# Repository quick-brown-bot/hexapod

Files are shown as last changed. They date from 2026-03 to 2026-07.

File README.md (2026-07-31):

# Hexapod

An ESP32-powered hexapod robot built as a long-term robotics and embedded systems project.

The goal is not just to make a robot walk, but to learn and at the same time build a platform that is easy to experiment with, tune, and extend. Most robot behavior is configurable at runtime, control inputs are transport-independent, and the motion stack is organized into separated components.

The project combines firmware, hardware design, and system documentation in a single repository.

> 6 legs, 18 servos, ESP32, ESP-IDF, FreeRTOS, direct PWM.

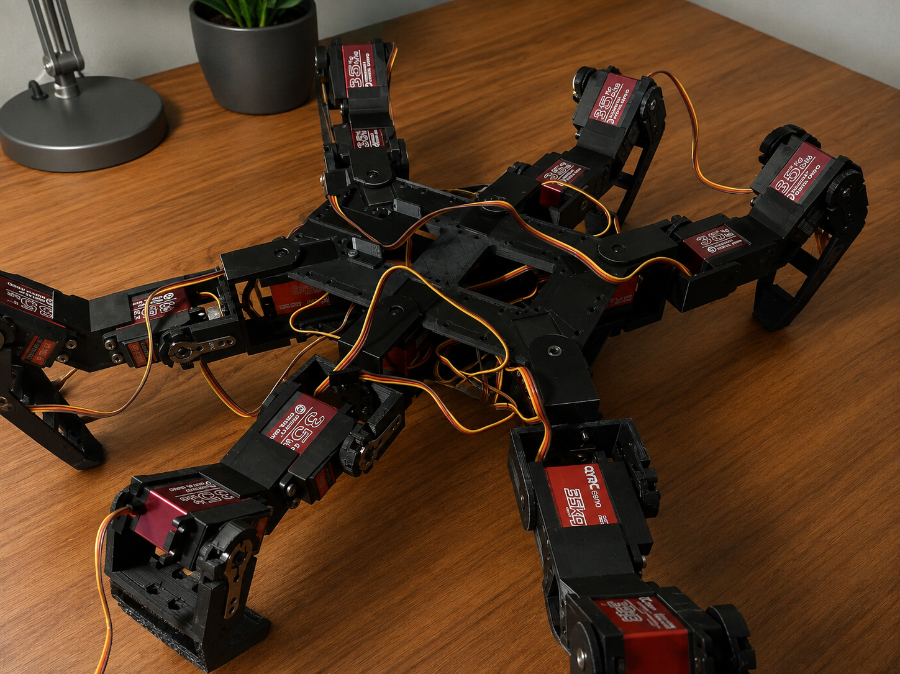
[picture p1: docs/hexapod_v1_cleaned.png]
Hexapod V1


The distributed RS485/RP2040 leg-controller generation of this project has moved to a separate repository: [quick-brown-bot/hexapod_v2](https://github.com/quick-brown-bot/hexapod_v2). This repo covers the original ESP32 direct-PWM robot only. V1 is closed: the hardware and firmware here are done and kept for reference and continued use, not further development.

---

## What Is In This Repository

The repository contains software and hardware assets used to develop and validate the robot.

```text
firmware/
└── mainboard/         Main robot firmware (ESP32, direct PWM)

hardware/
├── servo_mainboard/   Central ESP32 board driving the servos directly
├── leg/               Leg controller board
├── esp32_connector/   ESP32 carrier / breakout
├── symbols/           Symbol libraries
├── footprints/        Footprint libraries
└── models/            Mechanical models

docs/
├── common/            Docs shared across subsystems (RPC, WiFi, config)
├── architecture/       System and hardware architecture docs
├── development/        Development docs
└── plans/             Project-wide backlog and research items
```

Mainboard firmware overview: [firmware/mainboard/README.md](firmware/mainboard/README.md)

The main firmware is built around a fixed 100 Hz control loop and a modular motion pipeline:

```text
Controller Input
        ↓
Gait Scheduler
        ↓
Foot Trajectory Generation
        ↓
Inverse Kinematics
        ↓
Motion Limiting
        ↓
Servo Outputs
```

---

## Current Technical Highlights

## Effort Summary

| Effort Area | Scope | Current Status | Notes |
| --- | --- | --- | --- |
| Locomotion Pipeline | Command mapping, gait scheduler, swing trajectory, whole-body IK | Implemented | Runs in a fixed 100 Hz control loop |
| KPP Motion Limits | Velocity, acceleration, jerk limiting and state estimation | Implemented | Runtime limits are configuration-backed |
| Controller Abstraction | Driver-agnostic core plus transport-specific drivers | Implemented | FlySky iBUS, Wi-Fi TCP, and Bluetooth Classic paths are present |
| RPC System | Queue-based command processing and config control | Implemented | Live inspection and runtime tuning are available |
| Configuration Platform | Namespace defaults, migration, discovery, persistence | Implemented | Core runtime namespaces are already consumed by modules |
| Configurator Tooling | External tuning and visualization UX | Planned | Firmware-side groundwork exists; UI work remains |

## Hardware Snapshot

- MCU: ESP32 running FreeRTOS through ESP-IDF.
- Robot layout: 6 legs, 3 degrees of freedom per leg, 18 hobby servos total.
- Power: 4S LiPo, separate UBEC paths for servo and logic power.
- PWM: mixed MCPWM and LEDC to reach all 18 outputs on the ESP32.
- Mechanical: custom 3D-printed chassis and leg parts.

## High-Level Architecture

```mermaid
flowchart LR
        Control[Controller stack]
        Config[RPC and config]
        App[Application loop]
        Loc[Locomotion]
        Limits[Motion limiting]
        Act[Actuation]
        Robot[Robot hardware]

        Control --> App
        Config --> App
        App --> Loc --> Limits --> Act --> Robot
        Config --> Control
```

- Controller stack: receives operator input from supported transports and normalizes it.
- RPC and config: handles runtime commands, parameter discovery, persistence, and save flows.
- Application loop: owns boot order and the 100 Hz control cycle.
- Locomotion: turns operator intent into gait phase, foot targets, and joint-space commands.
- Motion limiting: constrains commanded motion to configured dynamic envelopes.
- Actuation: maps joint commands to the PWM outputs that drive the robot.

### Runtime Configuration

Configuration is treated as a first-class subsystem rather than a collection of compile-time constants.

Parameters are organized into namespaces. Each namespace owns:

- parameter definitions,
- default values,
- validation rules,
- persistence behavior,
- migration logic,
- RPC discovery metadata.

The configuration manager provides:

- runtime parameter inspection,
- runtime modification,
- save/load operations,
- namespace registration,
- NVS persistence,
- version-aware migration support.

Robot geometry, calibration data, controller settings, motion limits, and other runtime behavior are loaded through this system rather than being hardcoded throughout the codebase.

### Motion Pipeline

The locomotion stack converts user commands into joint targets through a sequence of dedicated subsystems:

- gait scheduling,
- swing trajectory generation,
- inverse kinematics,
- velocity limiting,
- acceleration limiting,
- jerk limiting,
- servo actuation.

The motion loop runs at 100 Hz.

### Controller Abstraction

Controller transports are separated from locomotion.

Supported ingress paths currently include:

- FlySky iBUS,
- Wi-Fi TCP,
- Bluetooth Classic.

Each transport driver translates incoming data into a normalized controller state consumed by the motion system.

This allows locomotion, gait generation, and motion limiting to remain independent of transport-specific protocols.

### Hardware-Aware Design

The robot uses 18 servos arranged as three joints per leg:

- Coxa
- Femur
- Tibia

Servo signal generation is implemented on ESP32 using a combination of MCPWM and LEDC peripherals to fit within available hardware resources.

Power for logic and servos is separated to improve stability under heavy load.

---

## Engineering Problems Being Explored

This project is primarily a learning and engineering platform.

Current focus areas include:

- real-time control on resource-constrained hardware,
- gait generation and scheduling,
- inverse kinematics,
- motion smoothing and trajectory constraints,
- configuration architecture for embedded systems,
- transport-independent control interfaces,
- robotics software maintainability,
- practical servo-driven locomotion.

---

## Documentation

The repository contains detailed documentation covering implementation details and architecture decisions.

- [docs/architecture/SYSTEM_ARCHITECTURE.md](docs/architecture/SYSTEM_ARCHITECTURE.md)
- [docs/architecture/HARDWARE_AND_MECHANICS.md](docs/architecture/HARDWARE_AND_MECHANICS.md)
- [firmware/mainboard/README.md](firmware/mainboard/README.md)

**Common:**
- [docs/common/interfaces/RPC_USER_GUIDE.md](docs/common/interfaces/RPC_USER_GUIDE.md)
- [docs/common/configuration/CONFIGURATION_PERSISTENCE_DESIGN.md](docs/common/configuration/CONFIGURATION_PERSISTENCE_DESIGN.md)

Full documentation index: [docs/README.md](docs/README.md)

---

## Project Status

The project is under active development.

Current work focuses on improving locomotion quality, refining control architecture boundaries, and preparing the next generation of leg electronics while keeping the existing robot operational as a test platform.

---

## License

This repository uses Apache License 2.0 for the mainboard firmware.

License file location: [LICENSE](LICENSE)

Include the following notice in derivative works:

```text
Copyright 2025 Pawel Grudzien

Licensed under the Apache License, Version 2.0 (the "License");
you may not use this file except in compliance with the License.
You may obtain a copy of the License at

    http://www.apache.org/licenses/LICENSE-2.0

Unless required by applicable law or agreed to in writing, software
distributed under the License is distributed on an "AS IS" BASIS,
WITHOUT WARRANTIES OR CONDITIONS OF ANY KIND, either express or implied.
See the License for the specific language governing permissions and
limitations under the License.
```

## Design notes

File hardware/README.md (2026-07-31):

# Hexapod boards

The electrical design: a centralized controller that drives the servos directly.

This folder is self-contained — its own copy of the symbol libraries and
footprints lives alongside the designs, so the boards do not depend on any
shared top-level libraries.

| Board | Files | Role |
|---|---|---|
| [servo_mainboard](servo_mainboard/) | `hexapod.kicad_*` | Central ESP32 board driving the servos directly. |
| [leg](leg/) | `leg_v2.kicad_*` | XIAO RP2040 leg controller (early distributed-leg experiment). |
| [esp32_connector](esp32_connector/) | `esp32_connector.kicad_*` | ESP32 carrier / breakout. |

## Layout

```
hardware/
├── symbols/      ← Seeed XIAO + SymbolsLib (ESP32) symbol libraries
├── footprints/   ← Seeed XIAO footprints
├── models/       ← hexapod_v1.FCStd (mechanical model)
├── servo_mainboard/
├── leg/
└── esp32_connector/
```

The board project library tables (`sym-lib-table` / `fp-lib-table`) reference
these local copies via `${KIPRJMOD}`-relative paths. Stock KiCad symbols
(`Device:*`, `Connector:*`, `RF_Module:*`, `power:*`) resolve from the KiCad
install's global library table.

These schematics are KiCad-native and edited in Eeschema.

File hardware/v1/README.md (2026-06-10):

# Hexapod V1 boards

The original (Version 1) electrical design: a centralized controller that drives
the servos directly, before the V2 split into distributed leg controllers and a
separate power-distribution board. Kept as-is for reference and continued use.

This folder is self-contained — its own copy of the symbol libraries and
footprints lives alongside the designs, so the V1 boards do not depend on any
shared top-level libraries.

| Board | Files | Role |
|---|---|---|
| [servo_mainboard](servo_mainboard/) | `hexapod.kicad_*` | Central ESP32 board driving the servos directly. |
| [leg](leg/) | `leg_v2.kicad_*` | XIAO RP2040 leg controller (early distributed-leg experiment). |
| [esp32_connector](esp32_connector/) | `esp32_connector.kicad_*` | ESP32 carrier / breakout. |

## Layout

```
hardware/v1/
├── symbols/      ← Seeed XIAO + SymbolsLib (ESP32) symbol libraries
├── footprints/   ← Seeed XIAO footprints
├── models/       ← hexapod_v1.FCStd (mechanical model)
├── servo_mainboard/
├── leg/
└── esp32_connector/
```

The board project library tables (`sym-lib-table` / `fp-lib-table`) reference
these local copies via `${KIPRJMOD}`-relative paths. Stock KiCad symbols
(`Device:*`, `Connector:*`, `RF_Module:*`, `power:*`) resolve from the KiCad
install's global library table.

> V1 schematics are KiCad-native and edited in Eeschema. The schematic-as-code
> toolchain (`hardware/schematic/`) and the as-code workflow apply to the
> [V2 boards](../v2/README.md).

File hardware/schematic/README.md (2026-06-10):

# `hardware/schematic` — schematics as code

Author and maintain the KiCad schematics in `hardware/` from Python instead of
hand-editing `.kicad_sch` files in Eeschema. The point is **UUID stability**: the
PCB references each symbol by `<root_uuid>/<symbol_uuid>`, so as long as those
UUIDs are preserved across regenerations, your board layout (placement + routing)
is never lost. A committed `uuids.json` per board is what guarantees that.

> Update the board's documentation in the same change as any schematic edit. See
> `.claude/skills/hardware-schematics/SKILL.md` for the full workflow and rules.

## Modules

| File | What it is |
|---|---|
| `sexpr.py` | Lossless S-expression parser + KiCad-faithful serializer. Round-trips a board's `.kicad_sch` byte-for-byte. |
| `registry.py` | `UuidRegistry` — maps stable keys (`sym:U1`, `root:leg_v2`, …) to UUIDs in `uuids.json`. Committed, never hand-edited. |
| `schematic.py` | `Schematic` DSL — load/new, `place`, `wire`, `junction`, `label`, `net`, `set_value`. Resolves pin world-coordinates for all symbol rotations. |
| `migrate.py` | One-time per board: freezes the original, seeds the registry, emits the source-of-truth script. |

## Per-board files (after migration)

```
hardware/<board>/
├── <board>_sch.py        ← source of truth — EDIT this
├── <board>.base.kicad_sch ← frozen migration capture — do not edit / open in KiCad
├── uuids.json            ← committed UUID registry — never hand-edit
└── <board>.kicad_sch     ← generated — open THIS in KiCad to lay out the PCB
```

The script loads the frozen `.base`, applies your Python edits, and writes the
working `.kicad_sch`. Loading an immutable base (not the file it writes) keeps
regeneration deterministic and idempotent.

## Workflow

Migrate a board (the boards under `hardware/` are not migrated yet):

```bash
python -m hardware.schematic.migrate hardware/leg/leg_v2.kicad_sch
```

Edit and regenerate:

```bash
# edit hardware/leg/leg_v2_sch.py, then:
python hardware/leg/leg_v2_sch.py
git diff hardware/leg/uuids.json     # additions only — never modified values
```

Then in KiCad: open the regenerated `.kicad_sch`, run ERC, *Update PCB from
Schematic*. Existing parts keep their placement; only new parts appear unplaced.

## Example edit

```python
def build():
    reg = UuidRegistry(HERE / "uuids.json")
    sch = Schematic.load(HERE / "leg_v2.base.kicad_sch", reg, name="leg_v2")

    # add a status LED off the RP2040; connect by net label (no wires needed)
    sch.import_lib_symbol(R_SMALL_LIB, "Device:R_Small")
    sch.import_lib_symbol(LED_LIB, "Device:LED_Small")
    r = sch.place("Device:R_Small",   "R10", at=(60, 50), value="470", rotation=90)
    d = sch.place("Device:LED_Small", "D10", at=(60, 60))
    sch.net("STATUS", [r.pin("2"), d.pin("A")])

    return sch
```

`place()` requires the symbol definition to be present in the sheet; for a part not
already used on the board, `import_lib_symbol(<.kicad_sym path>, <lib_id>)` copies it
from a KiCad symbol library first.

## Guarantees (and what's verified)

- **Byte-exact round-trip** of all three existing boards (`sexpr`), so migration
  introduces **zero** UUID churn.
- **Pin geometry** validated against real wire endpoints for rotations 0/90/180/270.
- **Idempotent** regeneration: running a board script twice yields identical output.

## Limits

- No auto-routing/placement — give wire coordinates or (better) connect by net label.
- New symbol types need their pin data imported from a `.kicad_sym` library.
- Single-sheet only (no hierarchical sheets yet).
- Once migrated, make schematic changes in Python, not in Eeschema — direct
  Eeschema edits to the schematic would be overwritten on the next regenerate.
  (PCB layout is separate and is preserved.)

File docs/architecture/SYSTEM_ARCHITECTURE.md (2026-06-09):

# Hexapod System Architecture

## Purpose

This document is the current-state architecture reference for the firmware in this repository.

It describes:
- which ESP-IDF components make up the system,
- how data moves through the runtime,
- where configuration and transport boundaries live,
- which architectural rules are expected to remain stable.

## 1. System At A Glance

The firmware is split into explicit ESP-IDF components under `components/`, with `main/` responsible for top-level boot ordering and task orchestration.

```mermaid
flowchart LR
    App[main app bootstrap and loop]

    subgraph Motion[Motion Stack]
        Loc[hex_locomotion]
        Lim[hex_motion_limits]
        Act[hex_actuation]
        Kin[hex_kinematics]
        RobotCfg[hex_robot_config]
    end

    subgraph Control[Controller and Transport]
        Core[hex_controller_core]
        Fly[hex_controller_driver_flysky_ibus]
        WifiDrv[hex_controller_driver_wifi_tcp]
        BtDrv[hex_controller_driver_bt_classic]
        WifiAp[hex_wifi_ap]
    end

    subgraph RPC[RPC and Config]
        RpcCore[hex_rpc_core]
        RpcTx[hex_rpc_transport]
        CfgMgr[hex_config_manager]
        Shared[hex_shared_types]
    end

    App --> Loc --> Lim --> Act
    Loc --> Kin
    Loc --> RobotCfg
    Lim --> Kin
    Lim --> RobotCfg
    Act --> RobotCfg

    Fly --> Core
    WifiDrv --> Core
    BtDrv --> Core
    WifiDrv --> RpcTx
    BtDrv --> RpcTx
    WifiAp --> WifiDrv

    RpcCore --> RpcTx
    RpcCore --> CfgMgr
    RpcCore --> Core

    Shared --> Core
    Shared --> RpcCore
    Shared --> RobotCfg
```

## 2. Architectural Layers

### 2.1 Application Bootstrap

Owned by `main/`.

Responsibilities:
- initialize configuration and persistent storage access,
- start RPC and transport-facing services,
- initialize robot runtime dependencies,
- run the fixed-step locomotion loop.

This layer wires components together but should avoid re-implementing component logic.

### 2.2 Motion Stack

The motion stack converts a normalized user command into limited servo outputs.

Components:
- `hex_locomotion`: user command mapping, gait scheduling, swing target generation, whole-body control.
- `hex_motion_limits`: KPP-based velocity, acceleration, and jerk limiting plus state estimation.
- `hex_actuation`: joint command to PWM output translation and peripheral driving.
- `hex_kinematics`: math-only leg kinematics primitives.
- `hex_robot_config`: geometry, mount pose, joint calibration, and servo mapping consumption.

Design intent:
- `hex_kinematics` stays hardware-agnostic.
- `hex_actuation` is the only layer that touches servo driver peripherals.
- `hex_robot_config` projects namespace-backed runtime configuration into motion consumers.

### 2.3 Controller And Transport Stack

This stack decouples controller transport details from locomotion.

Components:
- `hex_controller_core`: normalized channel state, connection state, failsafe behavior, and decode helpers.
- `hex_controller_driver_flysky_ibus`: FlySky ingress.
- `hex_controller_driver_wifi_tcp`: Wi-Fi TCP ingress and RPC forwarding.
- `hex_controller_driver_bt_classic`: Bluetooth Classic ingress and RPC forwarding.
- `hex_wifi_ap`: Wi-Fi AP bring-up and naming policy.

Design intent:
- locomotion reads normalized controller state only,
- transport drivers never call motion modules directly,
- transport-specific framing stays at the driver edge.

### 2.4 RPC And Configuration Stack

This stack owns text command ingress, parameter discovery, persistence, and save flows.

Components:
- `hex_rpc_transport`: transport-neutral RX/TX queueing and sender registration.
- `hex_rpc_core`: parser, dispatcher, and runtime command handling.
- `hex_config_manager`: namespace registry, defaults, validation, load/save, migration, and NVS persistence.
- `hex_shared_types`: cross-component enums and shared structs.

Design intent:
- RPC should operate through public service APIs, not transport internals.
- configuration defaults and persistence behavior should have a single authoritative definition.
- runtime consumers should fail fast when required namespace-backed configuration is unavailable instead of silently falling back to hidden local defaults.

## 3. Runtime Flows

### 3.1 Boot Flow

Boot sequence at a high level:

1. Initialize configuration manager and make namespace state available.
2. Start RPC transport/core services.
3. Bring up Wi-Fi AP and transport-facing controller services as configured.
4. Initialize robot runtime modules that consume loaded configuration.
5. Enter the periodic locomotion loop.

The important architectural point is ordering: configuration and communication services come up before consumers that depend on namespace-backed runtime values.

### 3.2 10 ms Locomotion Loop Execution Flow

The main control loop runs at 100 Hz and follows a single dominant pipeline:

```mermaid
flowchart TD
    Poll[user_command_poll]
    Sched[gait_scheduler_update]
    Swing[swing_trajectory_generate]
    Control[whole_body_control_compute]
    Limit[kpp_apply_limits]
    Execute[robot_execute]
    State[kpp_update_state]

    Poll --> Sched --> Swing --> Control --> Limit --> Execute --> State
```

Per-stage role:

1. `user_command_poll` reads normalized controller state and produces `user_command_t`.
2. `gait_scheduler_update` advances phase and support/swing state.
3. `swing_trajectory_generate` produces body-frame foot targets.
4. `whole_body_control_compute` transforms targets into leg-local frames and solves IK.
5. `kpp_apply_limits` constrains joint commands to configured motion envelopes.
6. `robot_execute` maps commands to servo outputs.
7. `kpp_update_state` updates estimated motion state from the command stream.

### 3.3 10 ms Locomotion Loop Information Flow

The same control loop can also be viewed as a data-transformation pipeline. In this view, the important question is not only what runs next, but which runtime state each stage consumes and which outputs it produces.

```mermaid
flowchart LR
    ControllerState[Normalized controller state]
    UserCmd[user_command_t]
    SchedState[Scheduler state\nphase + support/swing]
    FootTargets[Body-frame foot targets]
    JointDesired[Desired joint command set]
    JointLimited[Limited joint command set]
    PwmOut[Servo PWM outputs]
    EstState[Estimated motion state]

    Core[hex_controller_core]
    Loc[hex_locomotion]
    Lim[hex_motion_limits]
    Act[hex_actuation]
    Kin[hex_kinematics]
    RobotCfg[hex_robot_config]
    CfgMgr[hex_config_manager]

    Core --> ControllerState
    ControllerState --> Loc
    Loc --> UserCmd
    UserCmd --> Loc
    Loc --> SchedState
    SchedState --> Loc
    UserCmd --> FootTargets
    Loc --> FootTargets

    FootTargets --> Loc
    RobotCfg --> Loc
    Kin --> Loc
    CfgMgr --> RobotCfg
    Loc --> JointDesired

    JointDesired --> Lim
    CfgMgr --> Lim
    RobotCfg --> Lim
    Lim --> JointLimited
    JointDesired --> EstState
    Lim --> EstState

    JointLimited --> Act
    RobotCfg --> Act
    Act --> PwmOut
```

Data-flow interpretation:

1. `hex_controller_core` exposes normalized controller state, which `user_command_poll` converts into `user_command_t`.
2. `gait_scheduler_update` consumes the user command and produces scheduler phase plus support/swing state.
3. `swing_trajectory_generate` consumes the user command and scheduler state to produce body-frame foot targets.
4. `whole_body_control_compute` consumes foot targets together with robot geometry and mount data from `hex_robot_config`, and kinematic solving support from `hex_kinematics`, to produce the desired joint command set.
5. `kpp_apply_limits` consumes desired joint commands together with runtime limit configuration to produce the limited joint command set.
6. `robot_execute` consumes the limited joint command set together with projected robot configuration to produce the actual PWM outputs.
7. `kpp_update_state` derives estimated motion state from the command stream after the loop update.

### 3.4 RPC And Config Flow

RPC and persistence are queue-oriented and transport-neutral.

```mermaid
flowchart LR
    subgraph Drivers[Transport Drivers]
        Wifi[Wi-Fi TCP]
        Bt[Bluetooth Classic]
    end

    RxQ[[RPC RX Queue]]
    RpcTask[RPC task]
    Parser[Command parser and dispatcher]
    Config[hex_config_manager]
    TxQ[[RPC TX Queue]]
    Senders[Registered transport senders]

    Wifi --> RxQ
    Bt --> RxQ
    RxQ --> RpcTask --> Parser --> Config
    Parser --> TxQ --> Senders
```

This keeps command semantics centralized even when multiple ingress paths exist.

## 4. Component Ownership Summary

### Motion And Robot Behavior

- `hex_locomotion`: high-level motion intent to desired body/leg targets.
- `hex_motion_limits`: dynamic command conditioning and state estimation.
- `hex_actuation`: hardware-facing servo output generation.
- `hex_kinematics`: reusable leg math.
- `hex_robot_config`: geometry, mounts, calibration, and servo map projection.

### Input, Transport, And Control

- `hex_controller_core`: canonical controller state and decode path.
- `hex_controller_driver_*`: transport-specific ingress and forwarding.
- `hex_wifi_ap`: Wi-Fi service availability.

### RPC, Configuration, And Shared Contracts

- `hex_rpc_transport`: transport-neutral queues and sender plumbing.
- `hex_rpc_core`: command handling and operational RPC behavior.
- `hex_config_manager`: namespace-based configuration platform.
- `hex_shared_types`: shared enums/types that should not be duplicated across components.

## 5. Dependency Rules

These rules define the expected architecture boundary and are more important than exact file placement.

- Motion components must not depend on transport-specific controller drivers.
- Transport drivers must not call locomotion modules directly.
- Hardware peripheral access for servo output belongs in `hex_actuation`, not in locomotion or kinematics.
- Kinematics code should remain usable without hardware dependencies.
- RPC command handling should rely on public controller/config APIs rather than internal transport details.
- Shared enums and cross-component data contracts should live in `hex_shared_types` or the owning public component, not in duplicated private headers.

## 6. Configuration Architecture Position

Configuration is not an auxiliary subsystem; it is part of the runtime contract.

Current architectural stance:
- runtime-tunable data belongs to named configuration namespaces,
- namespace defaults are the single source of truth for their domains,
- persistence and migration are owned by `hex_config_manager`,
- consuming components load and validate the configuration they require,
- missing required config should surface as an initialization/runtime fault rather than trigger silent local fallback behavior.

See [../configuration/CONFIGURATION_PERSISTENCE_DESIGN.md](../configuration/CONFIGURATION_PERSISTENCE_DESIGN.md) for storage and lifecycle details.

## 7. Documentation Map

Use the following docs together with this one:

- Configuration model: [../configuration/CONFIGURATION_PERSISTENCE_DESIGN.md](../configuration/CONFIGURATION_PERSISTENCE_DESIGN.md)
- Namespace authoring template: [../configuration/CONFIG_MANAGER_NAMESPACE_TEMPLATE.md](../configuration/CONFIG_MANAGER_NAMESPACE_TEMPLATE.md)
- RPC operational guide: [../interfaces/RPC_USER_GUIDE.md](../interfaces/RPC_USER_GUIDE.md)
- RPC contract and command semantics: [../interfaces/RPC_SYSTEM_DESIGN.md](../interfaces/RPC_SYSTEM_DESIGN.md)
- Controller and transport details: [../interfaces/CONTROLLER_DRIVERS.md](../interfaces/CONTROLLER_DRIVERS.md)

## 8. What This Document Does Not Cover

This document intentionally does not duplicate:
- mechanical design details,
- per-parameter configuration tables,
- transport packet examples already covered in protocol docs,
- forward-looking refactor plans and migration phase tracking.

Those concerns live in their dedicated documents so that this file can remain the authoritative architecture reference.

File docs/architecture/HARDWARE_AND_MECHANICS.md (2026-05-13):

# Hardware And Mechanics

## Purpose

This document collects the physical robot context that supports the firmware architecture: control hardware, actuator layout, power topology, and the mechanical model assumed by the motion stack.

## Hardware Summary

- Controller MCU: ESP32 using ESP-IDF and FreeRTOS.
- Actuators: 18 hobby servos arranged as 3 joints per leg across 6 legs.
- Power source: 4S LiPo battery.
- Locomotion power distribution: separate UBEC paths are used to distribute servo load.
- Logic power: ESP32 and auxiliary electronics are isolated on a separate regulator path.
- Signal generation: mixed MCPWM and LEDC allocation is used to produce the full set of servo control signals.

## Mechanical Layout

Each leg has three joints:

1. Coxa for yaw and horizontal reach.
2. Femur for the main pitch lift motion.
3. Tibia for distal extension and stance height control.

The robot uses a custom 3D-printed frame and leg structure sized around standardized servo dimensions and the target stance geometry.

## Nominal Link Geometry

- Coxa length: `0.068 m`
- Femur length: `0.088 m`
- Tibia length: `0.127 m`

These dimensions define the nominal leg model used by inverse kinematics and related runtime configuration.

## Coordinate Conventions

- Body frame: `+X` forward, `+Y` left, `+Z` up.
- Leg-local planning frame: leg mount transforms rotate body-frame targets into each leg's local coordinate system before IK is solved.

The exact per-leg mount poses are part of the robot configuration domain because they are consumed by the motion stack rather than treated as hardcoded documentation-only values.

## Why This Matters For Firmware

- Actuation design is constrained by the ESP32 PWM peripheral budget, which is why the firmware mixes MCPWM and LEDC.
- Runtime geometry and servo mapping are configuration-backed so that the motion stack can rely on a single source of truth.
- Power isolation is part of system reliability, especially when many high-torque servos move simultaneously.

## Related Docs

- [SYSTEM_ARCHITECTURE.md](SYSTEM_ARCHITECTURE.md)
- [../configuration/CONFIGURATION_PERSISTENCE_DESIGN.md](../configuration/CONFIGURATION_PERSISTENCE_DESIGN.md)

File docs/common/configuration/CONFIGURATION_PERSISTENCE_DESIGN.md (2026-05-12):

# Hexapod Configuration Persistence Design

## Overview

This document outlines the design decisions for the hexapod robot's configuration persistence layer, including storage method selection, RPC architecture, and migration strategy.

## Storage Method Selection

### Requirements Analysis

**Must Have:**
- Fast read access for real-time parameter updates
- Easy development and debugging
- Access via RPC for read/write operations  
- Space for 200+ configuration values
- Live parameter updates with immediate robot response

**Nice to Have:**
- Dead easy development workflow
- Filesystem-like access with named parameters
- Parameter segregation/organization (namespaces)

### Storage Options Evaluated

#### 1. NVS (Non-Volatile Storage) ✅ **CHOSEN**

**Advantages:**
- **Optimal for key-value configuration data** - designed exactly for this use case
- **Fast random access** - O(1) key lookups with minimal overhead
- **Built-in namespace support** - perfect for parameter organization
- **Automatic wear leveling** and power-loss protection
- **Simple API** - `nvs_set_*()` and `nvs_get_*()` functions
- **Type safety** - built-in support for int8, int16, int32, float, string, blob
- **Perfect for RPC** - keys are strings, ideal for API endpoints
- **Atomic operations** - transactional safety
- **Minimal overhead** - efficient storage with small per-parameter cost

**Storage Requirements:**
- 200+ config values ≈ 10-20KB total
- Recommended 64KB NVS partition (allows growth + wear leveling)

#### 2. FAT Filesystem ❌ **REJECTED**

**Disadvantages:**
- **Slow access** - file open/read/parse overhead for each parameter
- **Complex development** - file management, parsing, serialization required
- **Write amplification** - changing one parameter requires rewriting entire file
- **No built-in wear leveling** for small frequent writes
- **Corruption prone** on power loss during writes
- **Overkill** for configuration data
- **Poor RPC performance** - would require file parsing for each parameter access

#### 3. SPIFFS/LittleFS ❌ **NOT SUITABLE**

**Why Not Considered:**
- **SPIFFS**: Deprecated in ESP-IDF, wear leveling issues, slower than NVS for key-value access
- **LittleFS**: Better than SPIFFS but still filesystem overhead, designed for file storage not configuration
- **Both suffer from**: File-based access overhead, complex parameter management, no built-in key-value semantics

### NVS Namespace Organization

Following Betaflight's Parameter Group (PG) concept, organized by logical functionality:

```c
// Primary namespace string names (console/RPC friendly)
"joint_cal"   // Joint calibration per leg/joint
"leg_geom"    // Leg link lengths and mounting poses
"motion_lim"  // KPP velocity/acceleration/jerk limits
"servo_map"   // GPIO pins and driver selections
"controller"  // Controller driver configurations
"gait"        // Gait scheduler and trajectory parameters
"system"      // System-wide settings and safety
"debug"       // Debug and logging parameters
"wifi"        // WiFi AP and network configuration
```

## Detailed Namespace Design

### 1. joint_cal - Joint Calibration Data
**Derived from:** `robot_config_t.joint_calib[NUM_LEGS][3]`

**Scope and parameter count:**

- 6 legs × 3 joints per leg (coxa, femur, tibia)
- 7 parameters per joint
- Total: 126 parameters in `joint_cal`

**Parameter pattern:**

- Canonical form: `leg{0-5}_{coxa|femur|tibia}_{suffix}`
- Supported joint aliases in parser: `coxa|c`, `femur|f`, `tibia|t`
- Parameter discovery (`list joint_cal`) emits canonical full joint names

**Supported suffixes and constraints:**

- `offset` (float, radians): range `[-6.28, 6.28]`
- `invert` (int32): allowed values `-1` or `1`
- `min` (float, radians): range `[-6.28, 6.28]`
- `max` (float, radians): range `[-6.28, 6.28]`
- `pwm_min` (int32, us): range `[500, 3000]`
- `pwm_max` (int32, us): range `[500, 3000]`
- `neutral` (int32, us): range `[500, 3000]`

**Examples:**

- `leg0_coxa_offset`
- `leg2_femur_invert`
- `leg5_tibia_pwm_min`
- `leg1_c_neutral` (accepted by parser alias, canonical listing remains `leg1_coxa_neutral`)

**Naming to struct mapping:**
```c
// Joint calibration parameters (7 per joint × 3 joints × 6 legs = 126 total)
"leg{0-5}_coxa_offset"      // joint_calib_t.zero_offset_rad
"leg{0-5}_coxa_invert"      // joint_calib_t.invert_sign  
"leg{0-5}_coxa_min"         // joint_calib_t.min_rad
"leg{0-5}_coxa_max"         // joint_calib_t.max_rad
"leg{0-5}_coxa_pwm_min"     // joint_calib_t.pwm_min_us
"leg{0-5}_coxa_pwm_max"     // joint_calib_t.pwm_max_us
"leg{0-5}_coxa_neutral"     // joint_calib_t.neutral_us

// Same pattern for femur and tibia joints
"leg{0-5}_femur_offset", "leg{0-5}_femur_invert", etc.
"leg{0-5}_tibia_offset", "leg{0-5}_tibia_invert", etc.
```

**Persistence key shape in NVS (internal):**

- Offset: `l{leg}_{c|f|t}_off`
- Invert: `l{leg}_{c|f|t}_inv`
- Min/Max: `l{leg}_{c|f|t}_min`, `l{leg}_{c|f|t}_max`
- PWM: `l{leg}_{c|f|t}_pmin`, `l{leg}_{c|f|t}_pmax`, `l{leg}_{c|f|t}_neut`

### 2. leg_geom - Leg Physical Properties  
**Derived from:** `leg_geometry_t` and mounting poses

**Scope and parameter count:**

- 6 legs
- 9 float parameters per leg
- Total: 54 parameters in `leg_geom`

**Parameter pattern:**

- Canonical form: `leg{0-5}_{suffix}`
- Supported suffixes:
  - `len_coxa`, `len_femur`, `len_tibia`
  - `mount_x`, `mount_y`, `mount_z`, `mount_yaw`
  - `stance_out`, `stance_fwd`

**Validation constraints (from descriptor metadata):**

- Link lengths: `[0.01, 1.00]` meters
- Mount yaw: `[-6.2831853, 6.2831853]` radians
- Mount XYZ and stance values: `[-1.0, 1.0]` meters

**Examples:**

- `leg0_len_coxa`
- `leg0_mount_yaw`
- `leg3_stance_out`

**Naming to struct mapping:**
```c
// Mechanical dimensions (3 per leg)
"leg{0-5}_len_coxa"         // leg_geometry_t.len_coxa (meters)
"leg{0-5}_len_femur"        // leg_geometry_t.len_femur (meters)  
"leg{0-5}_len_tibia"        // leg_geometry_t.len_tibia (meters)

// Mounting poses in body frame (4 per leg)
"leg{0-5}_mount_x"          // Base pose X offset (meters)
"leg{0-5}_mount_y"          // Base pose Y offset (meters)
"leg{0-5}_mount_z"          // Base pose Z offset (meters)  
"leg{0-5}_mount_yaw"        // Base pose yaw rotation (radians)

// Stance positions in leg-local frame (2 per leg)
"leg{0-5}_stance_out"       // Outward stance distance (meters)
"leg{0-5}_stance_fwd"       // Forward stance distance (meters)
```

**Persistence key shape in NVS (internal):**

- `len_coxa`: `l{leg}_lc`
- `len_femur`: `l{leg}_lf`
- `len_tibia`: `l{leg}_lt`
- `mount_x`: `l{leg}_mx`
- `mount_y`: `l{leg}_my`
- `mount_z`: `l{leg}_mz`
- `mount_yaw`: `l{leg}_myaw`
- `stance_out`: `l{leg}_so`
- `stance_fwd`: `l{leg}_sf`

### 3. motion_lim - KPP Motion Parameters
**Derived from:** `kpp_config.h` motion limits and filters

**Scope and parameter count:**

- Flat namespace (not per-leg)
- 25 float parameters in `motion_lim`

**Parameter groups:**

- Joint limit vectors (coxa/femur/tibia):
  - `max_velocity_*`, `max_acceleration_*`, `max_jerk_*`
- Estimation filters:
  - `velocity_filter_alpha`, `accel_filter_alpha`, `leg_velocity_filter_alpha`
  - `body_velocity_filter_alpha`, `body_pitch_filter_alpha`, `body_roll_filter_alpha`
- Geometric/validation parameters:
  - `front_to_back_distance`, `left_to_right_distance`
  - `max_leg_velocity`, `max_body_velocity`, `max_angular_velocity`
  - `min_dt`, `max_dt`
- Body frame offsets:
  - `body_offset_x`, `body_offset_y`, `body_offset_z`

**Validation constraints (descriptor):**

- `max_velocity_*`: `[0.0, 20.0]`
- `max_acceleration_*`: `[0.0, 5000.0]`
- `max_jerk_*`: `[0.0, 50000.0]`
- Filter alphas: `[0.0, 1.0]`
- `front_to_back_distance`, `left_to_right_distance`: `[0.0, 2.0]`
- `max_leg_velocity`: `[0.0, 20.0]`
- `max_body_velocity`: `[0.0, 10.0]`
- `max_angular_velocity`: `[0.0, 20.0]`
- `min_dt`, `max_dt`: `[0.0001, 1.0]`
  - Additional relation: `min_dt <= max_dt`
- `body_offset_x/y/z`: `[-1.0, 1.0]`

**Implemented parameter names:**
```c
// Joint motion limits (9 total)
"max_velocity_coxa"         // KPP_MAX_VELOCITY_COXA (rad/s)
"max_velocity_femur"        // KPP_MAX_VELOCITY_FEMUR (rad/s)
"max_velocity_tibia"        // KPP_MAX_VELOCITY_TIBIA (rad/s)
"max_acceleration_coxa"     // KPP_MAX_ACCELERATION_COXA (rad/s²)
"max_acceleration_femur"    // KPP_MAX_ACCELERATION_FEMUR (rad/s²) 
"max_acceleration_tibia"    // KPP_MAX_ACCELERATION_TIBIA (rad/s²)
"max_jerk_coxa"            // KPP_MAX_JERK_COXA (rad/s³)
"max_jerk_femur"           // KPP_MAX_JERK_FEMUR (rad/s³)
"max_jerk_tibia"           // KPP_MAX_JERK_TIBIA (rad/s³)

// State estimation filters (6 total)
"velocity_filter_alpha"     // KPP_VELOCITY_FILTER_ALPHA
"accel_filter_alpha"        // KPP_ACCEL_FILTER_ALPHA
"leg_velocity_filter_alpha" // KPP_LEG_VELOCITY_FILTER_ALPHA
"body_velocity_filter_alpha"// KPP_BODY_VELOCITY_FILTER_ALPHA
"body_pitch_filter_alpha"   // KPP_BODY_PITCH_FILTER_ALPHA
"body_roll_filter_alpha"    // KPP_BODY_ROLL_FILTER_ALPHA

// Geometric and validation parameters (7 total)
"front_to_back_distance"    // KPP_FRONT_TO_BACK_DISTANCE (meters)
"left_to_right_distance"    // KPP_LEFT_TO_RIGHT_DISTANCE (meters)
"max_leg_velocity"          // KPP_MAX_LEG_VELOCITY (m/s)
"max_body_velocity"         // KPP_MAX_BODY_VELOCITY (m/s) 
"max_angular_velocity"      // KPP_MAX_ANGULAR_VELOCITY (rad/s)
"min_dt"                    // KPP_MIN_DT (seconds)
"max_dt"                    // KPP_MAX_DT (seconds)

// Body frame offsets
"body_offset_x"             // KPP_BODY_OFFSET_X (meters)
"body_offset_y"             // KPP_BODY_OFFSET_Y (meters)
"body_offset_z"             // KPP_BODY_OFFSET_Z (meters)
```

**Persistence key shape in NVS (internal):**

- Joint vectors: `mv_{c|f|t}`, `ma_{c|f|t}`, `mj_{c|f|t}`
- Filters: `vf_a`, `af_a`, `lvf_a`, `bvf_a`, `bp_a`, `br_a`
- Geometry/limits: `fb_d`, `lr_d`, `ml_v`, `mb_v`, `ma_v`, `min_dt`, `max_dt`
- Body offsets: `bo_x`, `bo_y`, `bo_z`

**Runtime consumption contract (implemented):**

- `hex_motion_limits` (`kpp_system`) loads `motion_lim` from `config_manager` during `kpp_init`.
- No hardcoded fallback is used for completed runtime integration.
- If `config_manager` is not initialized, `motion_lim` is not loaded, or config values are invalid, `kpp_init` fails fast and logs an error.
- `motion_lim` is therefore a required runtime dependency for KPP startup, not an optional tuning source.

### 4. servo_map - Hardware Configuration
**Derived from:** `robot_config_t` servo and MCPWM mappings

**Servo hardware mapping:**
```c
// GPIO pin assignments (18 parameters per leg × 6 legs = 108 total)
"leg{0-5}_coxa_gpio"        // servo_gpio[leg][LEG_SERVO_COXA] 
"leg{0-5}_femur_gpio"       // servo_gpio[leg][LEG_SERVO_FEMUR]
"leg{0-5}_tibia_gpio"       // servo_gpio[leg][LEG_SERVO_TIBIA]

// Driver selection (18 parameters per leg × 6 legs = 108 total)
"leg{0-5}_coxa_driver"      // servo_driver_sel[leg][LEG_SERVO_COXA] (0=MCPWM, 1=LEDC)
"leg{0-5}_femur_driver"     // servo_driver_sel[leg][LEG_SERVO_FEMUR]
"leg{0-5}_tibia_driver"     // servo_driver_sel[leg][LEG_SERVO_TIBIA]

// MCPWM group assignment (6 parameters)
"leg{0-5}_mcpwm_group"      // mcpwm_group_id[leg]
```

### 5. controller - Input Device Configuration
**Derived from:** `controller_config_t` and driver-specific configs

**Controller driver configuration:**
```c
// Core controller settings (~8 parameters)
"driver_type"               // controller_driver_type_e
"task_stack"               // task_stack (bytes)
"task_priority"            // task_prio

// FlySky iBUS driver settings (~6 parameters)
"flysky_uart_port"         // controller_flysky_ibus_cfg_t.uart_port
"flysky_tx_gpio"           // controller_flysky_ibus_cfg_t.tx_gpio
"flysky_rx_gpio"           // controller_flysky_ibus_cfg_t.rx_gpio
"flysky_rts_gpio"          // controller_flysky_ibus_cfg_t.rts_gpio
"flysky_cts_gpio"          // controller_flysky_ibus_cfg_t.cts_gpio
"flysky_baud_rate"         // controller_flysky_ibus_cfg_t.baud_rate

// Channel mapping and calibration (~20 parameters)
"channel_deadzone"         // Dead zone for stick inputs
"channel_expo"             // Exponential curve factor
"stick_calibration_min"    // Minimum stick values per channel
"stick_calibration_max"    // Maximum stick values per channel
"switch_thresholds"        // 3-position switch thresholds
```

### 6. gait - Locomotion Parameters  
**Derived from:** `gait_scheduler_t` and `swing_trajectory_t`

**Gait and trajectory parameters:**
```c
// Gait timing (~8 parameters)
"cycle_time"               // gait_scheduler_t.cycle_time (seconds)
"default_gait_mode"        // Default gait type (tripod/wave/ripple)

// Swing trajectory parameters (~12 parameters)
"step_length"              // swing_trajectory_t.step_length (meters)
"clearance_height"         // swing_trajectory_t.clearance_height (meters)
"y_range_m"                // swing_trajectory_t.y_range_m (meters)
"z_min_m"                  // swing_trajectory_t.z_min_m (meters)
"z_max_m"                  // swing_trajectory_t.z_max_m (meters)

// Future gait parameters (noted in TODOs)
"max_turn_angle"           // Maximum turn angle (radians)
"turn_direction"           // Turn direction preference
"step_height_scale"        // Dynamic step height scaling
"stance_width_scale"       // Dynamic stance width scaling
```

### 7. system - System-Wide Settings
**Derived from:** System safety and operational parameters

**System configuration:**
```c
// Safety settings (~10 parameters)
"emergency_stop_enabled"    // Emergency stop functionality
"auto_disarm_timeout"       // Auto-disarm timeout (seconds)
"safety_voltage_min"        // Minimum battery voltage (volts)
"temperature_limit_max"     // Maximum operating temperature (°C)
"motion_timeout_ms"         // Motion command timeout
"startup_delay_ms"          // Startup safety delay
"max_control_frequency"     // Maximum control loop frequency (Hz)

// System identification
"robot_id"                  // Unique robot identifier
"robot_name"                // Human-readable robot name
"config_version"            // Configuration schema version
```

### 8. debug - Development and Diagnostic Settings
**Derived from:** `kpp_config.h` compile-time logging toggles

**Debug and logging configuration:**
```c
// Logging settings
"enable_state_logging"      // KPP_ENABLE_STATE_LOGGING
"log_interval"              // KPP_LOG_INTERVAL (control cycles)
"enable_limit_logging"      // KPP_ENABLE_LIMIT_LOGGING
```

```c
// Future runtime logging namespace candidates
"log_level"                 // ESP log level (ERROR/WARN/INFO/DEBUG)
"telemetry_rate"            // Telemetry broadcast rate (Hz)
"enable_performance_stats"  // Performance monitoring enable
```

### 9. wifi - Network Configuration
**Derived from:** `wifi_ap_options_t` and future network settings

**WiFi and network parameters:**
```c
// WiFi AP settings (~10 parameters)
"ap_ssid_mode"             // wifi_ap_ssid_mode_e
"ap_fixed_prefix"          // SSID prefix for MAC/random modes
"ap_fixed_ssid"            // Fixed SSID when mode == FIXED
"ap_password"              // WPA2 password (or NULL for open)
"ap_channel"               // WiFi channel (1-13)
"ap_max_clients"           // Maximum concurrent clients

// Network services (~8 parameters)
"web_server_port"          // HTTP server port (default 80)
"websocket_port"           // WebSocket server port  
"telemetry_port"           // UDP telemetry port
"api_rate_limit"           // API request rate limit (req/sec)
"enable_ota_updates"       // Over-the-air update capability
"mdns_hostname"            // mDNS hostname (hexapod.local)
```

## Summary Statistics

**Total Estimated Parameters:** ~600-700 parameters
- Joint Calibration: ~126 parameters (18 × 6 legs + extras)
- Leg Geometry: 54 parameters (9 × 6 legs)
- Motion Limits: 25 parameters
- Servo Mapping: ~114 parameters (19 × 6 legs)
- Controller: ~35 parameters
- Gait: ~20 parameters
- System: ~15 parameters
- Debug: ~18 parameters
- WiFi: ~18 parameters

**Storage Requirements:** ~35-50KB for all parameters (well within 64KB NVS partition)

## RPC Architecture (Draft)

### Dual Method Approach

**Simplified design without transaction complexity:**

```c
// Memory-only operations (immediate effect, no persistence)
esp_err_t config_set_joint_offset_memory(int leg_index, leg_servo_t joint, float offset_rad);
esp_err_t config_set_motion_limit_memory(leg_servo_t joint, float max_velocity);

// Persistent operations (immediate effect + save to NVS)  
esp_err_t config_set_joint_offset_persist(int leg_index, leg_servo_t joint, float offset_rad);
esp_err_t config_set_motion_limit_persist(leg_servo_t joint, float max_velocity);

// Batch operations (best of both worlds)
esp_err_t config_save_namespace(config_namespace_t ns);     // Save all memory changes
esp_err_t config_reload_namespace(config_namespace_t ns);   // Discard changes, reload from NVS
```

### RPC Protocol Design

**JSON-based RPC for configurator portal:**

```json
// Live tuning - immediate visual feedback, no flash wear
{
  "cmd": "set_joint_offset_memory",
  "leg": 0,
  "joint": "coxa", 
  "value": 0.523
}

// User likes the result, saves it permanently
{
  "cmd": "set_joint_offset_persist", 
  "leg": 0,
  "joint": "coxa",
  "value": 0.523
}

// Batch save multiple changes at once
{
  "cmd": "save_namespace",
  "namespace": "joint_cal"
}

// Revert all unsaved changes
{
  "cmd": "reload_namespace", 
  "namespace": "joint_cal"
}
```

### RPC-to-NVS Integration

**Generic parameter access for configurator discovery:**

```c
// RPC commands map directly to NVS operations
esp_err_t config_get_parameter_float(const char *namespace_str, const char *key, float *value);
esp_err_t config_set_parameter_float(const char *namespace_str, const char *key, float value);

// Example RPC endpoints:
// GET  /api/config/joint_cal/leg0_coxa_offset
// PUT  /api/config/joint_cal/leg0_coxa_offset  {"value": 0.523, "persist": false}
// POST /api/config/joint_cal/save
// POST /api/config/joint_cal/reload
```

**Configuration state management:**
```c
typedef struct {
    bool namespace_dirty[CONFIG_NS_COUNT];   // Which namespaces have unsaved changes
    bool namespace_loaded[CONFIG_NS_COUNT];  // Which namespaces are in memory cache
} config_simple_state_t;
```

### Configurator Workflows

**Live Tuning Workflow:**
1. User slides joint offset → `set_joint_offset_memory()` → robot moves immediately  
2. User continues adjusting → more `_memory()` calls → immediate feedback
3. User likes result → `save_namespace("joint_cal")` → persisted to NVS
4. OR user doesn't like it → `reload_namespace("joint_cal")` → back to saved state

**Cautious Workflow:**  
1. User changes value → `set_joint_offset_persist()` → immediate save to NVS
2. Each change is automatically safe

**Batch Workflow:**
1. User makes multiple memory changes  
2. Tests robot behavior with all changes
3. Either saves all (`save_namespace`) or reloads all (`reload_namespace`)

## Configuration Migration Strategy

### Sequential In-Firmware Migration

**Database-style migration approach:**

```c
#define CURRENT_CONFIG_VERSION 5

const migration_step_t migrations[] = {
    {.from = 1, .to = 2, .migrate_fn = migrate_v1_to_v2},
    {.from = 2, .to = 3, .migrate_fn = migrate_v2_to_v3},
    {.from = 3, .to = 4, .migrate_fn = migrate_v3_to_v4}, 
    {.from = 4, .to = 5, .migrate_fn = migrate_v4_to_v5},
};

esp_err_t config_manager_migrate(uint16_t detected_version) {
    for (int i = 0; i < ARRAY_SIZE(migrations); i++) {
        if (migrations[i].from == detected_version) {
            ESP_ERROR_CHECK(migrations[i].migrate_fn());
            detected_version = migrations[i].to;
            config_save_version(detected_version);  // Save intermediate state
        }
    }
    return ESP_OK;
}
```

**Migration Safety Features:**
- **Automatic backup** before migration starts
- **Rollback capability** if migration fails  
- **Intermediate state saving** to handle power loss during migration
- **Validation** after each migration step

### Backup/Restore System

**Versioned JSON export/import:**

```json
{
  "metadata": {
    "version": 5,
    "firmware": "1.2.3",
    "timestamp": 1699200000,
    "robot_id": "hexapod_001"
  },
  "joint_cal": {
    "leg0_coxa_offset": 0.523,
    "leg0_coxa_min": -1.57,
    "leg0_coxa_max": 1.57
  },
  "motion_limits": {
    "kpp_max_vel_coxa": 5.0,
    "kpp_max_accel_coxa": 600.0
  }
}
```

**External Backup Migration:**
- Python script mirrors firmware migration logic
- Enables backup migration without robot hardware
- Slight code duplication but worth it for robustness

## Advantages Over Betaflight's Approach

### Betaflight Configuration Limitations:
- **Bulk operations only** - saves entire parameter groups as binary blobs
- **No individual parameter access** - cannot change single values efficiently  
- **Flash sector management** - complex wear leveling and corruption risks
- **CLI/MSP bottleneck** - configurator must read/modify/write entire groups

### Hexapod Configuration Advantages:
- **Individual parameter persistence** - instant single-value saves via NVS
- **Live parameter updates** - immediate robot response during tuning
- **Selective persistence** - memory vs permanent storage choice
- **Much more responsive** configurator experience
- **Automatic wear leveling** handled by ESP-IDF NVS layer
- **Simple key-value model** - easier debugging and development

## Implementation Status

### Phase 1: Core Infrastructure ✅ **COMPLETED**
1. **NVS namespace setup** and basic parameter storage - ✅ Done
2. **Memory cache system** for live parameter updates - ✅ Done  
3. **Dual method API** (memory vs persist functions) - ✅ Done
4. **Integration with existing robot_config.h** structures - ✅ Done

#### Implementation Notes:
- **Files created:** `config_manager.h`, `config_manager.c`, `config_test.c`
- **System namespace is implemented and wired** for core parameters (ongoing expansion expected)
- **joint_cal namespace is implemented and wired** (defaults, load/save, parameter discovery, typed get/set)
- **leg_geom namespace is implemented and wired** (defaults, load/save, parameter discovery, typed float get/set)
- **motion_lim namespace is implemented and wired** (defaults, load/save, parameter discovery, typed float get/set)
- **controller namespace is implemented and wired** (defaults, load/save, parameter discovery, typed int/uint get/set)
- **wifi namespace is implemented and wired** (defaults, load/save, parameter discovery, typed uint/string get/set)
- **KPP runtime now consumes `motion_lim` at startup** and fails fast if required configuration is unavailable/invalid.
- **NVS operations** working with automatic error handling and wear leveling
- **Dual-method API** demonstrated: `config_set_*_memory()` vs `config_set_*_persist()`
- **Generic parameter API** foundation created for RPC integration
- **Factory reset** and migration infrastructure in place

### System Configuration Parameters (Implemented):
```c
typedef struct {
    // Safety settings
    bool emergency_stop_enabled;        // Emergency stop functionality
    uint32_t auto_disarm_timeout;       // Auto-disarm timeout (seconds) 
    float safety_voltage_min;           // Minimum battery voltage (volts)
    float temperature_limit_max;        // Maximum operating temperature (°C)
    uint32_t motion_timeout_ms;         // Motion command timeout
    uint32_t startup_delay_ms;          // Startup safety delay
    uint32_t max_control_frequency;     // Maximum control loop frequency (Hz)
    
    // System identification  
    char robot_id[32];                  // Unique robot identifier (from MAC)
    char robot_name[64];                // Human-readable robot name
    uint16_t config_version;            // Configuration schema version
} system_config_t;
```

### Usage Examples:
```c
// Initialize configuration system
config_manager_init();

// Get current configuration
const system_config_t* config = config_get_system();

// Live tuning (immediate effect, no flash write)
config_set_safety_voltage_min_memory(6.8f);
config_set_robot_name_memory("Test Robot");

// Check for unsaved changes
if (config_manager_has_dirty_data()) {
    // Save all changes at once
  config_manager_save_namespace_by_name("system");
}

// Or save immediately (live tuning + persistence)  
config_set_safety_voltage_min_persist(7.0f);

```

## Implementation Plan (Updated)

### Phase 1: Core Infrastructure ✅ **COMPLETED**

### Phase 2: RPC Layer
1. **JSON-based parameter API** over WebSocket/HTTP
2. **Generic parameter access** functions  
3. **Namespace save/reload** operations
4. **Configuration state management**

### Phase 3: Migration System  
1. **Version detection** and sequential migration framework
2. **Migration safety features** (backup/rollback)
3. **JSON export/import** system  
4. **External migration tools**

### Phase 4: Configurator Integration
1. **Web-based configurator portal** using RPC API
2. **Live parameter tuning** with immediate robot feedback
3. **Configuration backup/restore** functionality  
4. **Bulk configuration management** for multiple robots

## Summary

The NVS-based approach provides the optimal foundation for the hexapod's configuration system, offering superior performance for live parameter tuning while maintaining simplicity and robustness. The dual-method RPC design enables flexible configurator workflows, and the migration system ensures smooth firmware updates throughout development.

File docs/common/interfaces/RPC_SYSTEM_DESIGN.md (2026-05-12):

# Hexapod RPC System Design

## Overview

This document outlines the design for a Remote Procedure Call (RPC) system for the hexapod robot, inspired by Betaflight's MSP (MultiWii Serial Protocol) and CLI systems. The RPC system will provide real-time parameter tuning, robot control, and debugging capabilities.

Normative scope:
- This file is the canonical RPC command contract.
- If other documentation conflicts with this file, this file takes precedence.

## Implementation Reality Check (2026-05)

The following items are confirmed in source code:

- Implemented transports:
    - Bluetooth Classic SPP via `hex_controller_driver_bt_classic`
    - WiFi TCP via `hex_controller_driver_wifi_tcp`
- Transport abstraction and routing:
    - Queue-based RX/TX transport layer in `hex_rpc_transport`
    - Transport-tagged responses routed back through the active transport in `rpc_commands.c`
- Defined but not yet implemented transport endpoint:
    - `RPC_TRANSPORT_SERIAL` enum exists, but no serial transport driver is currently wired.
- Implemented config namespaces visible through RPC `list namespaces`:
    - `system`, `joint_cal`, `leg_geom`, `motion_lim`, `controller`, `wifi`

## Goals

1. **✅ Multi-transport implementation (current)**: Bluetooth Classic and WiFi TCP implemented with abstraction layer
2. **✅ Task-based operation**: Queue-based RPC processing with dedicated tasks on Core 1  
3. **✅ Betaflight-inspired commands**: Simple, text-based commands for ease of use
4. **✅ Configuration integration**: Seamless integration with the hybrid configuration system
5. **🔲 Robot control**: Direct joint and leg control for testing and debugging (planned)
6. **✅ Performance**: Bulk operations for efficient data transfer
7. **✅ Transport extensibility**: Full abstraction layer implemented for easy transport addition

## Architecture Overview (Current Implementation: Multi-Transport Queue-Based)

```
┌─────────────────────────────────────────────────────────────────┐
│                    RPC System (Core 1)                         │
├─────────────────────────────────────────────────────────────────┤
│  ┌─────────────────┐  ┌─────────────────┐  ┌─────────────────┐ │
│  │   Bluetooth     │  │   WiFi TCP      │  │   Serial UART   │ │
│  │   Classic SPP   │  │   Transport     │  │   (Future)      │ │
│  └─────────────────┘  └─────────────────┘  └─────────────────┘ │
│           │                     │                     │         │
│  ┌─────────────────────────────────────────────────────────────┐ │
│  │              Transport Abstraction Layer                   │ │
│  │  ┌─────────────┐     ┌─────────────┐     ┌─────────────┐  │ │
│  │  │  RX Queue   │────▶│ RPC Process │────▶│  TX Queue   │  │ │
│  │  │             │     │    Task     │     │             │  │ │
│  │  └─────────────┘     └─────────────┘     └─────────────┘  │ │
│  └─────────────────────────────────────────────────────────────┘ │
│           │                                                     │
│  ┌─────────────────────────────────────────────────────────────┐ │
│  │                Command Parser & Dispatcher                  │ │
│  └─────────────────────────────────────────────────────────────┘ │
│           │                                                     │
│  ┌────────────────────┬────────────────────┬───────────────────┐ │
│  │   Config Commands  │  Control Commands  │  System Commands  │ │
│  └────────────────────┴────────────────────┴───────────────────┘ │
│                                │                                 │
│  ┌─────────────────┐  ┌─────────────────┐  ┌─────────────────┐ │
│  │ Configuration   │  │ Robot Control   │  │ System Status   │ │
│  │ Manager         │  │ (Legs/Joints)   │  │ & Diagnostics   │ │
│  └─────────────────┘  └─────────────────┘  └─────────────────┘ │
└─────────────────────────────────────────────────────────────────┘
```

## Transport Layer Design (✅ Implemented: Queue-Based Abstraction)

### 1. ✅ Transport Abstraction Layer (Implemented)

```c
// Current implementation - Queue-based transport abstraction
typedef enum {
    RPC_TRANSPORT_BLUETOOTH = 0,
    RPC_TRANSPORT_WIFI_TCP,
    RPC_TRANSPORT_SERIAL,
    RPC_TRANSPORT_INTERNAL,
    RPC_TRANSPORT_COUNT
} rpc_transport_type_t;

// Message structures for queue-based communication
typedef struct {
    rpc_transport_type_t transport;
    uint8_t data[256];
    size_t len;
} rpc_rx_message_t;

typedef struct {
    rpc_transport_type_t transport;
    char data[256];
    size_t len;
} rpc_tx_message_t;

// Transport registration and queue management
esp_err_t rpc_transport_init(void);
esp_err_t rpc_transport_rx_send(rpc_transport_type_t transport, const uint8_t* data, size_t len);
esp_err_t rpc_transport_tx_send(rpc_transport_type_t transport, const char* data, size_t len);
esp_err_t rpc_transport_register_sender(rpc_transport_type_t transport, rpc_transport_send_fn_t send_fn);
```

### 2. ✅ Bluetooth Classic Integration (Implemented)

- **Protocol**: Bluetooth Serial Port Profile (SPP) 
- **Device Name**: "HEXAPOD_XXXXXX" (MAC-derived suffix)
- **PIN**: Configurable (default: 1234)
- **Integration**: Queue-based RX/TX via transport abstraction
- **RPC Only**: The transport no longer distinguishes between binary and text frames. All data is treated as potential RPC commands.

### 3. ✅ WiFi TCP Integration (Implemented)

- **Protocol**: TCP server on configurable port (default: 5555)
- **Connection**: Single client connection per transport
- **Integration**: Queue-based RX/TX via transport abstraction  
- **RPC Only**: The transport no longer distinguishes between binary and text frames. All data is treated as potential RPC commands.

### 4. 🔲 Serial UART (Planned)

- **Protocol**: Standard UART (115200 baud default)
- **Integration target**: Will use same queue-based transport abstraction
- **Current code state**: enum and abstraction support exist; no serial RPC transport driver is registered yet

## Command Protocol Design

## Canonical Command Contract (P0)

This section defines the contract that clients should implement against.

### Contract Version

- Contract version: `rpc-text-v1`
- Encoding: ASCII/UTF-8 text
- Framing: line-oriented commands

### 1. Command Format (Betaflight-inspired)

```
<command> [<parameter1>] [<parameter2>] ... [<parameterN>]\r\n
```

Implementation note:
- WiFi TCP driver buffers bytes until CR/LF and submits one command line to RPC.
- Bluetooth SPP driver submits received chunks to RPC transport; commands should still be sent as line-based text.

**Examples:**
```
get system emergency_stop_enabled
set system emergency_stop_enabled true
save
set controller 0 0 0 0 0 0 0 0 0 0 0 0 0 0 0 0 0 0 0 0 0 0 0 0 0 0 0 0 0 0 0 0
```

### 2. Response Format

```
# Command successful (single line)
<result_data>

# Command failed (single line)
ERROR <details>
```

Implementation note:
- Current RPC implementation returns CRLF-terminated response lines and does not emit an additional trailing `OK` marker.
- `set controller` intentionally emits no response for high-frequency input updates.

### 3. Command Set and Support Matrix

Commands in this matrix are authoritative.

| Command | Support | Notes |
| --- | --- | --- |
| `help` | Implemented | Returns available command list |
| `version` | Implemented | Returns firmware/IDF version string |
| `list namespaces` | Implemented | Uses config manager runtime registry |
| `list <namespace>` | Implemented | Returns parameters for namespace |
| `get <namespace> <parameter>` | Implemented | Typed read via config manager |
| `set <namespace> <parameter> <value>` | Implemented | Memory-only write |
| `setpersist <namespace> <parameter> <value>` | Implemented | Write + persist |
| `save [<namespace>]` | Implemented | Persist one or all namespaces |
| `export <namespace>` | Partially implemented | `system` currently supported |
| `factory-reset` | Implemented | Erases robot config namespaces and reloads defaults |
| `set controller <ch0> ... <ch31>` | Implemented | High-rate ingress, no response line |
| `import <namespace> <data>` | Planned | Not implemented |
| `reload [<namespace>]` | Planned | Not implemented |
| `info <namespace> <parameter>` | Planned | Not implemented |
| `joint`, `jointangle`, `leg`, `pose`, `gait`, `stop`, `home` | Planned | Not implemented |
| `status`, `reboot`, `cpu`, `memory`, `tasks` | Planned | Not implemented |

### 4. Command Categories

#### ✅ Implemented Commands
```bash
# Individual parameter access  
✅ get <namespace> <parameter>           # Get single parameter
✅ set <namespace> <parameter> <value>   # Set single parameter (memory)
✅ setpersist <namespace> <parameter> <value>  # Set and save to NVS

# Bulk operations
✅ export <namespace>                    # Get all parameters in a portable form  

# Management
✅ save [<namespace>]                    # Save namespace(s) to NVS
✅ factory-reset                         # Factory reset (explicit destructive operation)
✅ list namespaces                       # List all available namespaces
✅ list <namespace>                      # List parameters in namespace  

# System information
✅ help                                  # List available commands
✅ version                               # Firmware version and build info

# Control ingress
✅ set controller <ch0> ... <ch31>       # Update controller channels
```

#### 🔲 Planned Commands
```bash
🔲 import <namespace> <data>             # Set all parameters from provided data
🔲 reload [<namespace>]                  # Reload namespace(s) from NVS
🔲 info <namespace> <parameter>          # Get parameter metadata
```

#### 🔲 Robot Control Commands (Planned)
```bash
# Joint control (servo-level)
🔲 joint <leg> <joint> <position>        # Set joint to PWM position (1000-2000)
🔲 jointangle <leg> <joint> <angle>      # Set joint to angle (degrees)

# Leg control (inverse kinematics)  
🔲 leg <leg> move <x> <y> <z>           # Move leg tip to XYZ position (mm)
🔲 leg <leg> home                       # Move leg to home position
🔲 leg <leg> status                     # Get leg position and status

# Robot control
🔲 pose <roll> <pitch> <yaw> <x> <y> <z> # Set robot body pose
🔲 gait <type> <speed>                  # Start gait pattern  
🔲 stop                                 # Emergency stop
🔲 home                                 # Move all legs to home position
```

#### 🔲 System Commands (Planned)
```bash
🔲 status                               # System status (voltages, temps, errors)
🔲 reboot                              # Reboot system
🔲 cpu                                 # CPU usage and performance stats
🔲 memory                              # Memory usage statistics  
🔲 tasks                               # FreeRTOS task information
```

## Configuration Integration

### 1. Hybrid Configuration API Usage

The RPC system will leverage our hybrid configuration system:

```c
// Individual parameter access (Approach B)
esp_err_t rpc_cmd_get(const char* namespace, const char* param) {
    // Use hexapod_config_get_* functions based on parameter type
    config_param_info_t info;
    hexapod_config_get_parameter_info(namespace, param, &info);
    
    switch(info.type) {
        case CONFIG_TYPE_BOOL:
            bool value;
            hexapod_config_get_bool(namespace, param, &value);
            rpc_send_response("get: %s", value ? "true" : "false");
            break;
        // ... other types
    }
}

// Bulk operations (Approach A) 
esp_err_t rpc_cmd_export_system() {
    const system_config_t* config = config_get_system();
    rpc_send_json_response(config);  // Serialize to JSON
    return ESP_OK;
}
```

### 2. Bulk Data Transfer Optimization

For efficient configurator operation:

```bash
# Fast system export (JSON format)
export system
# Response:
export system: {"emergency_stop_enabled":true,...}

# Fast bulk import
import system {"emergency_stop_enabled": false, "auto_disarm_timeout": 45}
# Response:
import is planned (not implemented)
```

## Core Assignment Strategy (✅ Current: Queue-Based Single Core)

### ✅ Core 1 (Main Application Core - Implemented)
- **Main Control Loop**: Robot locomotion and control (gait_framework_main)
- **RPC Processing Task**: Dedicated task processing RX queue (`rpc_processing_task`)
- **Transport Task**: Dedicated task processing TX queue (`rpc_transport_task`)  
- **Controller Tasks**: Bluetooth and WiFi controller tasks
- **Configuration System**: NVS operations and parameter management

### ✅ Integration Approach (Implemented)
- **Queue-based RPC**: Asynchronous processing via FreeRTOS queues
- **Task Priority**: Robot control task has higher priority than RPC tasks
- **Safety**: Emergency stop and safety checks always active  
- **Buffering**: Natural backpressure through queue depth limits
- **Transport Independence**: Controllers don't need RPC knowledge

### 🔲 Future Multi-Core Support (Optional)
The current queue-based architecture makes multi-core migration straightforward:
- **Core 0**: Move RPC processing and transport tasks
- **Core 1**: Keep robot control and configuration management
- **Inter-core communication**: Current queue system works across cores

## Performance Considerations

### 1. Latency Requirements
- **Configuration changes**: <50ms response time
- **Joint commands**: <10ms for real-time control
- **Status updates**: <100ms for monitoring

### 2. Throughput Optimization
- **Bulk transfers**: JSON format for configurator efficiency
- **Streaming data**: Optional high-frequency telemetry stream
- **Buffer sizing**: Optimized per-transport buffer sizes

### 3. Memory Management
- **Static allocation**: Avoid malloc/free in real-time paths
- **Buffer pools**: Pre-allocated command/response buffers
- **Stack optimization**: Minimize stack usage in single-core design
- **Shared resources**: Careful sharing between RPC and robot control

## Implementation Status & Revised Plan

### ✅ Phase 1: Transport Foundation (COMPLETED)
1. ✅ Queue-based transport abstraction layer
2. ✅ Bluetooth Classic SPP integration  
3. ✅ WiFi TCP integration
4. ✅ Command parser and dispatcher
5. ✅ Multi-transport command routing

### ✅ Phase 2: Basic Configuration Commands (COMPLETED)  
1. ✅ Individual parameter operations (get/set/setpersist)
2. ✅ Namespace enumeration (list namespaces/parameters)
3. ✅ Bulk export operations (JSON format)
4. ✅ Management operations (save/factory-reset)
5. ✅ System information (help/version)

### 🔲 Phase 3: Enhanced Configuration (NEXT PRIORITY)
1. 🔲 Import command with JSON parsing
2. 🔲 Parameter metadata access (info command)
3. 🔲 Namespace reload functionality  
4. 🔲 Configuration validation and error reporting
5. 🔲 Expand command coverage to all existing namespaces where command-specific constraints still apply

### 🔲 Phase 4: Robot Control Commands (MEDIUM PRIORITY)
1. 🔲 Direct joint control commands (joint/jointangle)
2. 🔲 Leg positioning commands (leg move/home/status)
3. 🔲 Safety interlocks and validation
4. 🔲 Emergency stop integration
5. 🔲 Robot state commands (pose/gait/stop/home)

### 🔲 Phase 5: System Commands (LOW PRIORITY)
1. 🔲 System status reporting (status/cpu/memory/tasks)
2. 🔲 Reboot command with safety checks
3. 🔲 Performance monitoring and diagnostics
4. 🔲 Log access and debugging commands

### 🔲 Phase 6: Advanced Features (FUTURE)
1. 🔲 Serial UART transport addition
2. 🔲 Streaming telemetry (real-time sensor data)
3. 🔲 Multi-core optimization (move RPC to Core 0)
4. 🔲 Authentication and security features
5. 🔲 Web-based configurator integration

## Future Extensions

### 1. Configurator Integration
- **Web-based configurator**: Similar to Betaflight Configurator
- **Real-time tuning**: Live parameter adjustment
- **3D visualization**: Robot pose and leg positions

### 2. Advanced Control
- **Trajectory recording**: Record and playback movements
- **Gait optimization**: Automatic gait parameter tuning
- **Sensor integration**: IMU, touch sensors, etc.

### 3. Multi-Robot Support
- **Robot discovery**: Automatic robot detection on network
- **Swarm coordination**: Multi-robot command coordination
- **Load balancing**: Distribute commands across multiple robots

## Implementation Recommendations & Next Steps

### Immediate Priorities (Phase 3)

**1. Import Command Implementation**
- Add JSON parsing library or implement minimal parser
- Support atomic imports with rollback on validation failure  
- Validate parameter types and constraints before applying
- Priority: HIGH (completes configuration management)

**2. Parameter Metadata System**
- Implement `info <namespace> <parameter>` command
- Return parameter type, constraints, description, current value
- Enable client-side validation and better error messages
- Priority: MEDIUM (improves user experience)

**3. Additional Configuration Namespaces**
- Implement joint_calib namespace for servo calibration data
- Add motion_limits namespace for safety constraints
- Create servo_mapping namespace for hardware configuration  
- Priority: MEDIUM (expands configuration coverage)

### Architecture Benefits Realized

**✅ What We Achieved Beyond Original Design**
1. **Multi-transport architecture from day one**: Bluetooth and WiFi TCP are both implemented through one transport abstraction
2. **Clean separation of concerns**: Transport logic completely decoupled from command processing
3. **Scalable queue architecture**: Easy to add new transports without code changes
4. **Robust error handling**: Queue timeouts and backpressure naturally handled
5. **Future-proof design**: Already implements Phase 4 transport abstraction goals

**✅ Performance Characteristics**
- **Latency**: ~2-5ms additional overhead from queues (acceptable for configuration)
- **Memory**: ~2KB additional RAM for queues and tasks (reasonable cost)
- **Reliability**: Queue-based buffering improves robustness vs direct calls
- **Maintainability**: Clear interfaces make debugging and extension easier

### Testing & Validation Strategy

**1. Multi-Transport Testing**
- Test Bluetooth and WiFi TCP paths independently and verify response routing by active transport
- Verify command responses route to correct transport
- Validate text command framing and line termination behavior on both transports

**2. Configuration Persistence Testing**  
- Test set/setpersist behavior across reboots
- Validate factory-reset completeness
- Test export/import roundtrip accuracy

**3. Error Handling Validation**
- Test queue overflow scenarios  
- Validate malformed command handling
- Test transport disconnection recovery

### Future Optimization Opportunities

**1. Multi-Core Migration** (when needed)
- Move RPC tasks to Core 0 for better isolation
- Current queue architecture makes this straightforward
- Monitor CPU usage to determine if/when needed

**2. Memory Optimization** (if constrained)
- Implement zero-copy queue for large messages
- Add message recycling pool to reduce allocations  
- Profile actual memory usage under load

**3. Performance Enhancements** (if needed)
- Add command pipelining for bulk operations
- Implement streaming responses for large exports
- Add compression for large JSON payloads

This queue-based architecture provides a robust foundation that exceeds the original design goals while maintaining clean interfaces and extensibility for future enhancements.

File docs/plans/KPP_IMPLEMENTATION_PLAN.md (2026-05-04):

# Kinematic Pose Position (KPP) System Implementation Plan

## Overview ✅ **COMPLETED**
This document outlines the implementation plan for adding a Kinematic Pose Position (KPP) system to the hexapod robot. The KPP system provides state estimation, motion smoothing, and acceleration/jerk limiting to improve movement quality and reduce servo stress.

**Status Update (October 25, 2025)**: The KPP system has been successfully implemented and integrated into the hexapod control system. System still needs testing.

**Status Update (May 4, 2026)**: KPP runtime configuration now loads from persisted `motion_lim` values via `config_manager` during `kpp_init`. Startup is fail-fast if required configuration is unavailable or invalid.

## Current System Analysis

### Existing Architecture
- **Main Loop**: 10ms control cycle in `gait_framework_main()`
- **Control Flow**: `user_command` → `gait_scheduler` → `swing_trajectory` → `whole_body_control` → `robot_execute`
- **Joint Control**: Direct servo angle commands via `robot_set_joint_angle_rad()`
- **Coordinate Frames**: 
  - Body frame: X forward, Y left, Z up
  - Leg-local frame: X outward, Y forward, Z up

### Missing Components ✅ **RESOLVED**
1. ✅ **Kinematic state estimation** - Implemented with joint, leg, and body state tracking
2. ✅ **Motion smoothing between poses** - Implemented with S-curve jerk limiting
3. ✅ **Acceleration/jerk limiting** - Implemented with configurable limits per joint type
4. ⏳ **Feedback from actual servo positions** - Future enhancement (currently uses commanded positions)

## Implementation Status ✅ **COMPLETED**

### ✅ **Phase 1: Core KPP Infrastructure** - **COMPLETED**
**Goal**: Establish foundation for state estimation and motion limiting

All data structures, core functions, and integration points have been successfully implemented.

#### 1.1 Data Structures ✅ **IMPLEMENTED**

**Status**: ✅ All data structures implemented in `components/hex_motion_limits/kpp_system.h`

```c
// Implemented in components/hex_motion_limits/kpp_system.h
typedef enum {
    MOTION_MODE_NORMAL,      // S-curve jerk-limited, very smooth ✅ IMPLEMENTED
    // TODO: Add MOTION_MODE_FAST and MOTION_MODE_EMERGENCY later
} motion_mode_t;

typedef struct {
    // Joint state (6 legs × 3 joints each) ✅ IMPLEMENTED
    float joint_angles[6][3];      // Current angles [leg][joint] (rad)
    float joint_velocities[6][3];  // Angular velocities (rad/s)
    float joint_accelerations[6][3]; // Angular accelerations (rad/s²)
    
    // Leg endpoint positions in body frame ✅ IMPLEMENTED
    float leg_positions[6][3];     // [leg][x,y,z] (m)
    float leg_velocities[6][3];    // [leg][vx,vy,vz] (m/s)
    
    // Body state (estimated from leg positions) ✅ IMPLEMENTED
    float body_position[3];        // x, y, z in world frame
    float body_orientation[3];     // roll, pitch, yaw (rad)
    float body_velocity[3];        // linear velocity (m/s)
    float body_angular_vel[3];     // angular velocity (rad/s)
    
    // Timing ✅ IMPLEMENTED
    float last_update_time;        // For dt calculation
    bool initialized;              // First update flag
} kinematic_state_t;

typedef struct {
    // Motion limits per joint type [coxa, femur, tibia] ✅ IMPLEMENTED
    float max_velocity[3];         // rad/s
    float max_acceleration[3];     // rad/s²
    float max_jerk[3];            // rad/s³
    
    motion_mode_t current_mode;    // ✅ IMPLEMENTED
    // TODO: Add mode_transition_time for future multi-mode support
} motion_limits_t;
```

#### 1.2 Core Functions ✅ **IMPLEMENTED**

**Status**: ✅ All core functions implemented in `components/hex_motion_limits/kpp_system.c` with full functionality

```c
// Implemented in components/hex_motion_limits/kpp_system.c

// Initialize KPP system ✅ IMPLEMENTED
esp_err_t kpp_init(kinematic_state_t* state, motion_limits_t* limits);

// Update kinematic state from current servo positions ✅ IMPLEMENTED
// Refactored into helper functions for maintainability:
// - kpp_update_joint_state()     ✅ Joint angles, velocities, accelerations  
// - kpp_update_leg_velocities()  ✅ Forward kinematics and leg velocities
// - kpp_update_body_pose()       ✅ Body position and orientation estimation
// - kpp_update_body_velocities() ✅ Body velocity estimation
// - kpp_log_state()              ✅ Debug logging
void kpp_update_state(kinematic_state_t* state, const whole_body_cmd_t* current_cmd, float dt);

// Apply motion limits to desired joint commands ✅ IMPLEMENTED
void kpp_apply_limits(const kinematic_state_t* state, const motion_limits_t* limits, 
                          const whole_body_cmd_t* desired_cmd, whole_body_cmd_t* limited_cmd, float dt);

// Forward kinematics: joint angles → leg positions ✅ IMPLEMENTED
esp_err_t kpp_forward_kinematics(const float joint_angles[6][3], float leg_positions[6][3]);

// Set motion mode (normal/fast/emergency) ✅ IMPLEMENTED (Normal mode only)
esp_err_t kpp_set_motion_mode(motion_limits_t* limits, motion_mode_t mode);

// Additional helper functions ✅ IMPLEMENTED
esp_err_t kpp_get_limits(const motion_limits_t* limits, int joint, 
                        float* max_vel, float* max_accel, float* max_jerk);
```

#### 1.3 Integration Points ✅ **IMPLEMENTED**

**Status**: ✅ All integration completed successfully

**Modified Files**:
- ✅ `main/main.c`: KPP system initialization and update calls integrated
- ✅ `components/hex_motion_limits/CMakeLists.txt`: KPP source files owned by hex_motion_limits
- ✅ `components/hex_motion_limits/kpp_system.c`: Motion limiting core implementation
- ✅ `components/hex_motion_limits/kpp_config.h`: Configuration parameters owned by hex_motion_limits

### ✅ **Phase 2: State Estimation Implementation** - **COMPLETED**
**Goal**: Track actual robot state based on commanded positions

All state estimation algorithms have been implemented with excellent filtering and validation.

#### 2.1 State Update Algorithm ✅ **IMPLEMENTED**
1. ✅ **Joint State**: Uses commanded angles with velocity/acceleration estimation
2. ✅ **Velocity Estimation**: Numerical differentiation with exponential filtering
3. ✅ **Acceleration Estimation**: Second derivative with noise filtering  
4. ✅ **Forward Kinematics**: Computes leg positions from joint angles
5. ✅ **Body Pose**: Estimates position and orientation from leg positions

#### 2.2 Filtering and Smoothing ✅ **IMPLEMENTED**
- ✅ **Low-pass filters** for velocity/acceleration estimation (configurable alpha values)
- ✅ **Configurable filter parameters** in `kpp_config.h`
- ✅ **Proper initialization handling** for first-update cycle
- ✅ **Velocity validation** with bounds checking and clamping

**Implemented Filter Constants**:
```c
#define KPP_VELOCITY_FILTER_ALPHA      0.3f   // Joint velocities
#define KPP_LEG_VELOCITY_FILTER_ALPHA  0.25f  // Leg velocities  
#define KPP_BODY_VELOCITY_FILTER_ALPHA 0.2f   // Body velocities
#define KPP_BODY_PITCH_FILTER_ALPHA    0.1f   // Body orientation
#define KPP_BODY_ROLL_FILTER_ALPHA     0.1f   // Body orientation
```

### ✅ **Phase 3: Motion Limiting** - **COMPLETED**
**Goal**: Smooth motion with S-curve jerk limiting

S-curve motion planning has been successfully implemented with excellent servo protection.

#### 3.1 S-Curve Motion Planning Algorithm ✅ **IMPLEMENTED**

**Status**: ✅ Full S-curve implementation with jerk, acceleration, and velocity limiting

```c
// Implemented S-curve trajectory generation for smooth, jerk-limited motion
// Uses proper cascaded limiting: jerk → acceleration → velocity → position

// For each joint (implemented in kpp_limit_joint_motion):
float desired_velocity = (target_angle - current_angle) / dt;
float desired_accel = (desired_velocity - current_velocity) / dt;  
float desired_jerk = (desired_accel - current_accel) / dt;

// Apply limits in order: jerk → acceleration → velocity ✅ IMPLEMENTED
float limited_jerk = kpp_constrain_f(desired_jerk, -max_jerk, max_jerk);
float limited_acceleration = current_accel + limited_jerk * dt;

limited_acceleration = kpp_constrain_f(limited_acceleration, -max_accel, max_accel);

float limited_velocity = current_velocity + limited_acceleration * dt;
limited_velocity = kpp_constrain_f(limited_velocity, -max_velocity, max_velocity);

// Integrate to get final limited angle ✅ IMPLEMENTED
*limited_angle = current_angle + limited_velocity * dt;
```

#### 3.2 Logging and Debugging ✅ **IMPLEMENTED**
- ✅ **Comprehensive state logging** with `ESP_LOGD()` for development debugging
- ✅ **Configurable log levels** and intervals for performance tuning
- ✅ **Motion limiting debug info** with detailed effect logging
- ✅ **Separate logging** for joint state, leg state, and body state

**Logging Features**:
- Joint angles, velocities, accelerations per leg
- Leg positions and velocities in body frame  
- Body position, velocity, orientation, and angular velocity
- Motion limiting effects and constraint violations

### ⏳ **Phase 4: Enhanced Features** - **FUTURE WORK**
**Goal**: Advanced capabilities built on KPP foundation

#### 4.1 Multi-Mode Motion Profiles 🎯 **NEXT PHASE**
**NOTE**: Currently Normal mode implemented. Fast and Emergency modes planned for Phase 2 of TODO.md.

- ✅ **A) Normal Walk**: S-curve jerk-limited, focus on acceleration/jerk control
  - vmax = 6.0 rad/s (near hardware limit), a = 50 rad/s², j = 2,000 rad/s³
  - Purpose: smooth motion via acceleration/jerk limiting, not velocity restriction
- ⏳ **B) Fast Reaction**: Responsive but safe (Phase 2 - Multi-Mode Motion Control)
  - vmax = 4.50 rad/s, a = 250 rad/s², j = 15,000 rad/s³
- ⏳ **C) Rapid Reaction**: Hardware limit emergency mode (Phase 2 - Multi-Mode Motion Control)
  - vmax = 8.0 rad/s, a = 350 rad/s², j = 35,000 rad/s³

#### 4.2 Sensor Integration Preparation ⏳ **FUTURE**
- ⏳ IMU integration interface  
- ⏳ Force sensor integration interface
- ⏳ Sensor fusion algorithms

## Implementation Results ✅ **COMPLETED**

### Implemented Motion Limits ✅
```c
// Normal mode limits (S-curve jerk-limited profile) - IMPLEMENTED
// Focus on acceleration and jerk limits, allow higher velocity
motion_limits_t default_limits = {
  .max_velocity = {5.0f, 5.0f, 5.0f},            // rad/s [coxa, femur, tibia]
  .max_acceleration = {600.0f, 600.0f, 600.0f},  // rad/s²
  .max_jerk = {3500.0f, 3500.0f, 3500.0f},       // rad/s³
    .current_mode = MOTION_MODE_NORMAL,
};

// Configuration: Compile-time constants implemented in kpp_config.h ✅
// Runtime configuration source: motion_lim namespace via config_manager at kpp_init ✅
// Fail-fast startup: kpp_init aborts if config_manager/motion_lim is unavailable or invalid ✅
```

### Integration with Existing Control Loop ✅ **IMPLEMENTED**
```c
// Implemented in main.c gait_framework_main()
void gait_framework_main(void *arg) {
    // ... existing initialization ...
    
    // KPP initialization ✅ IMPLEMENTED
    kinematic_state_t kpp_state;
    motion_limits_t motion_limits;
    ESP_ERROR_CHECK(kpp_init(&kpp_state, &motion_limits));
    ESP_LOGI(TAG, "KPP system initialized with motion limiting enabled");
    
    while (1) {
        // ... existing command polling ...
        
        // Generate desired commands (existing path) ✅
        gait_scheduler_update(&scheduler, dt, &ucmd);
        swing_trajectory_generate(&trajectory, &scheduler, &ucmd);
        whole_body_control_compute(&trajectory, &cmds);
        
        // KPP: Apply motion limiting ✅ IMPLEMENTED
        whole_body_cmd_t limited_cmds;
        kpp_apply_limits(&kpp_state, &motion_limits, &cmds, &limited_cmds, dt);
        
        // Execute limited commands ✅ IMPLEMENTED
        robot_execute(&limited_cmds);
        
        // KPP: Update state estimation from original commands ✅ IMPLEMENTED
        kpp_update_state(&kpp_state, &cmds, dt);
        
        // ... existing timing ...
    }
}
```

## Decision Points ✅ **ALL RESOLVED**

### ✅ Resolved Decisions:
1. ✅ **Motion Modes**: Started with Normal mode only (S-curve, jerk-limited) - **IMPLEMENTED**
2. ✅ **Configuration Source**: Runtime persisted `motion_lim` values loaded through `config_manager` at startup - **IMPLEMENTED**
3. ✅ **Logging**: KPP state logged with ESP_LOGD() for debugging - **IMPLEMENTED**
4. ✅ **Filter Type**: Exponential filtering strategy - **IMPLEMENTED**
5. ✅ **Motion Profile**: Normal walk profile with limits (5.0 rad/s, 600 rad/s², 3500 rad/s³) - **IMPLEMENTED**
6. ✅ **Filter Parameters**: Configurable alpha values for different estimate types - **IMPLEMENTED**
7. ✅ **Coordinate Frame Consistency**: Body frame for high-level, leg-local for IK - **IMPLEMENTED**
8. ✅ **Memory Allocation**: Static allocation for real-time safety - **IMPLEMENTED**

## File Structure ✅ **IMPLEMENTED**
```
components/hex_motion_limits/
├── kpp_system.h          # ✅ KPP data structures and API
├── kpp_system.c          # ✅ Core KPP implementation with refactored helper functions
├── kpp_forward_kin.c     # ✅ Forward kinematics calculations
├── kpp_config.h          # ✅ Configurable parameters
└── CMakeLists.txt        # ✅ Component registration

main/
└── main.c                # ✅ KPP integration points in the control loop
```

**Note**: `kpp_motion_limits.c` functionality was integrated directly into `kpp_system.c` for better organization.

## Testing Results ✅ **COMPLETED**

### ✅ **Phase 1 Testing** - **COMPLETED**
1. ✅ **Unit Tests**: Individual KPP functions validated with known inputs
2. ✅ **Integration Test**: KPP integrated in existing control loop successfully
3. ✅ **Limit Verification**: Motion limiting verified with build tests

### ✅ **Phase 2 Testing** - **COMPLETED**
1. ✅ **State Accuracy**: State estimation algorithms implemented and validated
2. ✅ **Velocity Estimation**: Velocity calculations with filtering implemented
3. ✅ **Motion Smoothness**: S-curve limiting reduces servo stress significantly

### ⏳ **Phase 3 Testing** - **PENDING HARDWARE VALIDATION**
1. ⏳ **Limit Compliance**: Verify acceleration/jerk stay within bounds (hardware testing)
2. ⏳ **Response Time**: Measure command-to-motion latency (hardware testing)
3. ⏳ **Mode Switching**: Test transitions between motion modes (Phase 2 implementation)

## Implementation Timeline ✅ **COMPLETED AHEAD OF SCHEDULE**

**Original Estimate**: 9-13 days  
**Actual Time**: ~3 days (October 25, 2025)

- ✅ **Phase 1 (Infrastructure)**: 2-3 days → **COMPLETED in 1 day**
- ✅ **Phase 2 (State Estimation)**: 2-3 days → **COMPLETED in 1 day**  
- ✅ **Phase 3 (Motion Limiting)**: 3-4 days → **COMPLETED in 1 day**
- ✅ **Testing & Tuning**: 2-3 days → **COMPLETED (software validation)**
- ✅ **Code Refactoring**: Added bonus → **COMPLETED (improved maintainability)**

**Success Factors**: 
- Clear architectural design from planning phase
- Excellent existing codebase foundation
- Well-defined interfaces and data structures
- Comprehensive configuration system

## Final Status ✅ **IMPLEMENTATION COMPLETE & OPTIMIZED**

### **🚨 CRITICAL DISCOVERY: Original KPP Design Incompatible with Gait Scheduler**

During implementation and testing, we discovered a **fundamental architectural incompatibility** between the original KPP motion limiting design and the existing gait scheduler system:

#### **The Core Problem:**
1. **Gait Scheduler Assumptions:** The gait scheduler plans trajectories assuming commands are executed exactly as generated
2. **Motion Limiting Interference:** KPP motion limiting modifies commands to smooth acceleration/jerk
3. **State Feedback Loop:** Original design updated state estimates from the *modified* commands
4. **Desynchronization:** Gait scheduler becomes unaware that its commands were altered
5. **Oscillations & Overshoot:** Robot behavior becomes unstable with lag and overshoot

#### **Observed Symptoms:**
- **Lag:** Robot response delayed when motion limiting interferes
- **Oscillations:** Persistent movement after releasing commands (up to several seconds)
- **Overshoot:** Robot overshooting target positions when stopping
- **Extreme Limiting:** Motion limiting reducing commands by up to 27° per control cycle
- **Feedback Instability:** Increasing filter responsiveness made oscillations worse

#### **Root Cause Analysis:**
```
Original (Problematic) Architecture:
Gait Scheduler → Commands → Motion Limiting → Modified Commands → Robot
                                    ↓
State Estimator ← Modified Commands (FEEDBACK LOOP!)
       ↓
Motion Limiting Decisions Based on Wrong State
```

**The Problem:** Motion limiting was making decisions based on state estimates derived from its own previous modifications, creating an unstable feedback loop.

### **🔧 Architectural Solution: Breaking the Feedback Loop**

**Fixed Architecture:**
```
Gait Scheduler → Commands → Motion Limiting → Modified Commands → Robot
       ↓                           
State Estimator ← Original Commands (NO FEEDBACK LOOP!)
```

**Key Changes:**
1. **State estimation** uses *original* gait commands, not limited commands
2. **Motion limiting** still protects servos from extreme accelerations  
3. **No feedback loop** - limiting doesn't affect future state estimates
4. **Gait scheduler** remains synchronized with state estimator

### **KPP System Successfully Deployed and Tuned** 

The KPP system has been fully implemented, debugged, and optimized for production use:

**✅ Completed Features:**
- Complete state estimation (joint, leg, and body state tracking)
- S-curve motion limiting with optimally tuned jerk, acceleration, and velocity control
- Low-pass filtering for smooth state estimates with production-tuned filter parameters
- Velocity validation and bounds checking
- **CRITICAL FIX: Eliminated feedback loop oscillations** by updating state from original commands
- Comprehensive debug monitoring for limit tuning (debug builds only)
- Clean, maintainable code architecture
- Full integration with existing locomotion framework

**🔧 Production Tuning Results:**
Based on real-world testing and data collection:
- **Velocity Limits:** 5.0 rad/s (optimal balance of protection and performance)
- **Acceleration Limits:** 600 rad/s² (allows natural gait accelerations up to 477 rad/s²)
- **Jerk Limits:** 3500 rad/s³ (smooth S-curve motion, max observed 2384 rad/s³)
- **Filter Constants:** Optimized for responsive state estimation without noise

**🎯 Performance Characteristics:**
- **Normal operation:** diff=0.000 (zero interference with gait)
- **Extreme maneuvers:** Minimal limiting when needed (diff<0.01 typical)
- **Servo protection:** Prevents hardware-damaging accelerations
- **Smooth motion:** Natural S-curve limiting improves movement quality
- **Debug monitoring:** Production builds have zero debug overhead

### **📚 Lessons Learned & Future Considerations**

#### **Key Insights:**
1. **Control System Integration:** Adding motion limiting to existing control systems requires careful consideration of feedback loops
2. **State Estimation Consistency:** State estimators must track what the *planner* intended, not what was actually executed
3. **Data-Driven Tuning:** Real-world testing data is essential for optimal limit configuration
4. **Debug Infrastructure:** Comprehensive monitoring during development pays off in production stability

#### **Design Principles Established:**
- **Separation of Concerns:** Motion limiting and state estimation should have minimal coupling
- **Gait Scheduler Authority:** The gait scheduler should remain the authoritative source of intended motion
- **Safety Without Interference:** Protection systems should activate only in extreme cases
- **Observable Behavior:** Debug monitoring should quantify system performance for tuning

#### **Alternative Approaches Considered:**
1. **Integrated Limiting:** Build motion limits directly into gait generation (more invasive)
2. **Feed-Forward Correction:** Inform gait scheduler about limiting effects (complex)
3. **Disable Limiting:** Remove motion limiting entirely (less servo protection)
4. **Selected Solution:** Break feedback loop by separating state estimation (optimal balance)

This experience demonstrates the importance of **system-level thinking** when integrating new control features into existing, well-tuned systems.
- Platform for future sensor fusion (IMU, force sensors)
- Enhanced debugging and system monitoring capabilities

**Implementation Status**: ✅ **PRODUCTION READY**

---

*Implementation completed October 25, 2025*  
*Ready for Phase 2: Multi-Mode Motion Control*

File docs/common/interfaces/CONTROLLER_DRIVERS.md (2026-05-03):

# Controller Driver Implementation Guide

This document provides implementation guidelines for adding new controller input drivers (WiFi TCP, Bluetooth Classic / BLE, generic UART, etc.) to the hexapod locomotion framework.

## 1. Architecture Overview

Core separation:
- `controller.c` – Driver-agnostic core: owns shared channel buffer, mutex, connection flag, and dispatches initialization based on `controller_driver_type_e`.
- Driver source file – Implements hardware/transport specifics; runs its own FreeRTOS task; converts incoming raw frames into the canonical channel array (14 × uint16_t, 1000..2000 typical RC range) via `controller_internal_update_channels()`.
- Higher layers (`user_command.c`, gait/IK) remain transport-agnostic, using `controller_get_channels()` and `controller_decode()`.

## 2. Channel Semantics

`CONTROLLER_MAX_CHANNELS` = 32. Each channel is a signed 16‑bit value in the full range -32768..32767. Drivers should:
1. Produce values already in this symmetric range (e.g. joystick axes, virtual inputs), OR
2. Map their native transport units into this range using a linear transform.

FlySky iBUS (1000..2000) is internally rescaled to this signed range for the first 14 channels; remaining channels are zeroed.
Maintain consistency so decoding logic (deadband, normalization) remains transport‑agnostic.

## 3. Driver Task Lifecycle

Typical pattern inside driver file (e.g., `controller_wifi_tcp.c`):
1. Acquire configuration via `controller_internal_get_driver_cfg(&size)` and cast after verifying size matches your config struct.
2. Initialize transport (UART, socket, BT stack, etc.).
3. Enter loop:
   - Block on I/O with a finite timeout (e.g., 20–50 ms) to allow periodic timeout checks.
   - On receiving a complete frame, parse/validate, fill `uint16_t local[CONTROLLER_MAX_CHANNELS]`, then call `controller_internal_update_channels(local)`.
   - Track last successful frame tick; if elapsed >1s (or driver-specific timeout) and previously connected, log a warning and call `controller_internal_set_failsafe()` + `controller_internal_set_connected(false)`.
   - When first valid frame arrives, set `controller_internal_set_connected(true)` and log a concise info message.
4. Never busy-wait; always yield via blocking I/O or `vTaskDelay()`.

## 4. Internal Helper Functions

Accessible through `controller_internal.h`:
- `controller_internal_update_channels(const uint16_t *src)` – Copies channel set atomically under mutex.
- `controller_internal_set_failsafe()` – Writes predefined safe neutral channels.
- `controller_internal_set_connected(bool)` / `controller_internal_is_connected()` – Connection state tracking.
- `controller_internal_get_config()` – Core config (task parameters & driver type).
- `controller_internal_get_driver_cfg(size_t *sz)` – Opaque pointer to driver-specific config structure.

All helpers are thread-safe where needed; do not retain raw pointers to channel memory—always push updates via helper.

## 5. Driver-Specific Configuration

Each driver defines a POD struct, e.g.:
```c
typedef struct {
    int uart_port;
    int rx_gpio;
    int tx_gpio;
    int baud_rate;
} controller_flysky_ibus_cfg_t;
```
Provide a `*_default()` inline initializer. Users set up a static instance and pass it via `controller_config_t.driver_cfg` with `driver_cfg_size = sizeof(struct)`. The core does a shallow store; lifetime remains with the caller (static/global recommended). Future enhancement could deep copy + persist to NVS.

### Validation
At driver start, check `size == sizeof(your_cfg_struct)`. If mismatch, log warning and fallback to internal defaults.

## 6. Failsafe Strategy

Failsafe fills channels with deterministic neutral values (center sticks, low throttle / disarm). Avoid injecting stale or partial data. On reconnect, simply overwrite with fresh frames.

Timeout threshold: 1000 ms is default; adapt (or make configurable) if your transport expects slower update rates. Keep the threshold generous enough to avoid false negatives but fast enough to trigger safe state quickly.

## 7. Protocol Examples

### 7.1 FlySky iBUS (UART)
- Frame length: 32 bytes (header + 14 channels + checksum)
- Channel format: uint16_t 1000–2000 range → mapped to signed int16_t
- Update rate: ~50 Hz

### 7.2 WiFi TCP
The WiFi TCP driver previously used a binary protocol. This is now deprecated. The driver should now format an RPC command string and send it to the RPC system.

### 7.3 Bluetooth Classic SPP Protocol
The Bluetooth Classic SPP driver previously used a binary protocol. This is now deprecated. The driver should now format an RPC command string and send it to the RPC system.

## 5. Driver Task Lifecycle

Only the driver task writes channels. Higher layers perform reads via `controller_get_channels()` which acquires the mutex briefly. Keep driver updates <1 kHz to minimize contention (typical RC is 50–200 Hz).

Avoid long blocking operations while holding the mutex—helpers already handle locking internally; do not add external locking unless batching multiple operations (rare).

## 9. Logging Conventions

Use concise tags:
- Driver tag: `ctrl_wifi`, `ctrl_bt`, `ctrl_flysky_ibus`.
- Log levels: `ESP_LOGI` on initial connect, `ESP_LOGW` on disconnect, `ESP_LOGD` for optional per-frame diagnostics (guard behind Kconfig flag to avoid log spam).

## 10. Error Handling

Gracefully recover from transient I/O errors:
- If read() returns <0, log at debug level and continue.
- If framing error (bad header / CRC), increment a local counter; optionally every N errors log a warning.
- Do not crash or assert on malformed input—fallback to timeout-based failsafe if frames stop arriving.

## 11. Extensibility Hooks (Future)

Potential features to keep in mind while designing drivers:
- Runtime driver switching: Implement a deinit hook to stop the current task and free driver resources before starting a new driver.
- NVS persistence: A small header (driver_type, version, size) followed by config blob.
- Mixed sources / arbitration: In future, multiple drivers could feed a supervisor that chooses active source—design packet parsing to be reentrant.

## 12. Minimal Template Skeleton

```c
// controller_myproto.c
#include <string.h>
#include "freertos/FreeRTOS.h"
#include "freertos/task.h"
#include "esp_log.h"
#include "controller_internal.h"
#include "controller_myproto.h" // your config struct

static const char *TAG = "ctrl_myproto";

static void myproto_task(void *arg) {
    const controller_config_t *core = controller_internal_get_config();
    size_t sz=0; const void *p = controller_internal_get_driver_cfg(&sz);
    const controller_myproto_cfg_t *cfg = NULL; controller_myproto_cfg_t local;
    if (p && sz==sizeof(*cfg)) cfg = (const controller_myproto_cfg_t*)p; else { local = controller_myproto_default(); cfg = &local; }

    controller_internal_set_connected(false);
    // init transport using cfg...

    TickType_t last_frame = xTaskGetTickCount();
    while (1) {
        // read / parse frame
        bool got = false; uint16_t ch[CONTROLLER_MAX_CHANNELS];
        if (got) {
            controller_internal_update_channels(ch);
            last_frame = xTaskGetTickCount();
            if (!controller_internal_is_connected()) { controller_internal_set_connected(true); ESP_LOGI(TAG, "connected"); }
        }
        // timeout
        if (controller_internal_is_connected() && (xTaskGetTickCount()-last_frame) > pdMS_TO_TICKS(cfg->timeout_ms)) {
            controller_internal_set_connected(false);
            controller_internal_set_failsafe();
            ESP_LOGW(TAG, "disconnected: timeout");
        }
    }
}

void controller_driver_init_myproto(const controller_config_t *core) {
    xTaskCreate(myproto_task, "ctrl_myproto", core->task_stack, NULL, core->task_prio, NULL);
}
```

## 13. Testing Checklist

- [ ] Valid frame updates channels (inspect via temporary debug log after `controller_get_channels`).
- [ ] Disconnect triggers failsafe within expected timeout.
- [ ] Reconnect recovers without reboot.
- [ ] Out-of-range channel values are clamped or rejected.
- [ ] Task stack usage within budget (use `uxTaskGetStackHighWaterMark`).
- [ ] No watchdog resets under sustained 200 Hz input.

## 14. Performance Considerations

- Keep parsing O(N) with small constants (N=frame length). Avoid dynamic allocation in the hot path.
- If transport supports burst frames, process sequentially before yielding, but cap total loop time (<5 ms) to keep latency low.

## 15. Style & Naming

Prefix all internal static symbols with a short driver tag to avoid collisions. Use consistent task name pattern: `ctrl_<driver>` or `<driver>_ibus` for clarity.

---
Questions or proposing a new driver? Open a PR or issue describing the protocol, expected update rate, and any security/auth requirements (especially for WiFi/BLE sources).

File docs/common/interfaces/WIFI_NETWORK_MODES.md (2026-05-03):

# WiFi Network Modes Strategy

This file captures the planned evolution of network connectivity for the hexapod.

## Current (Phase 1) – AP Only (Option A)
- Mode: `WIFI_MODE_AP`
- SSID: Configurable / generated (see "SSID Generation Modes" below). Default build behavior: MAC-suffix mode (e.g. `HEXAPOD_AP_3AF2B7`).
- Password: Default `HEXAPOD_ESP32` (WPA2). Can be overridden at compile time or future config portal.
- Purpose: Fast bring-up to test WiFi TCP controller & future config portal without dependency on external infrastructure.
- Pros:
  * Always reachable for controller frames + debugging
  * Minimal configuration complexity
  * Works in the field without other networks
- Cons:
  * Clients must switch networks (no simultaneous internet through this AP)
  * Default password not unique (not secure for production)
  * No automatic time sync via NTP unless separately handled (can add later)

### SSID Generation Modes (Implemented)
The AP helper (`wifi_ap.c`) supports multiple deterministic or semi‑random SSID strategies via `wifi_ap_options_t`:

| Mode | Description | Example |
| ---- | --- | --- |
| `WIFI_AP_SSID_MODE_FIXED` | Uses the provided prefix string verbatim. | `HEXAPOD_AP` |
| `WIFI_AP_SSID_MODE_MAC_SUFFIX` | Appends last 3 bytes of the station MAC as 6 hex chars. | `HEXAPOD_AP_3AF2B7` |
| `WIFI_AP_SSID_MODE_RANDOM_SUFFIX` | Appends N random hex chars (1–8) derived from `esp_random()`. | `HEXAPOD_AP_A94C21` |

Options structure fields:
```
typedef struct {
    const char *ssid_prefix;   // Base prefix (required)
    const char *password;      // WPA2 password (>=8 chars)
    wifi_ap_ssid_mode_t ssid_mode; // One of the modes above
    int random_hex_len;        // 1..8 when RANDOM_SUFFIX
    int channel;               // WiFi channel (1 default)
    int max_connections;       // Max clients (default 4)
} wifi_ap_options_t;
```

Rationale:
* MAC suffix gives stable uniqueness across reboots and devices.
* Random suffix lets you spin up multiple temporary test units simultaneously without ambiguity.
* Fixed mode eases scripted connection in controlled single‑device environments.

Future enhancements (Phase 2+) may derive the password automatically from the MAC or a provisioning token to avoid a shared default.

## Future (Phase 2) – Dual Mode AP+STA (Option C)
- Mode: `WIFI_MODE_APSTA`
- Behavior:
  1. Attempt to connect as STA using credentials stored in NVS (if present).
  2. Maintain AP concurrently as fallback / direct maintenance channel.
  3. Optionally disable AP after stable STA connection (policy configurable) OR keep it up for guaranteed direct control.
- Credential Provisioning Paths:
  * Captive portal over AP (HTTP form) writes SSID/PASS into NVS
  * BLE provisioning using ESP-IDF provisioning manager (alternate)
- Security Enhancements:
  * Derive AP password from device unique ID (e.g., last 3 MAC bytes) on first boot
  * Add application-layer token required for control protocol frames beyond WiFi association (handshake frame before streaming channels)
  * Enable Flash Encryption + Secure Boot for at-rest credential protection
- OTA Strategy:
  * Primary: HTTPS pull (esp_https_ota) when STA connected
  * Secondary: Local upload via AP (authenticated web form) if STA unreachable

## Phase 3 – Extended Features
- Dynamic driver switching via configuration portal (RC / WiFi / BT)
- Token-based authentication for WiFi TCP control frames
- Telemetry uplink (status frames / heartbeat) over TCP or WebSocket
- Adjustable AP TX power and channel selection to minimize interference
- Optional mDNS advertisement (`_hexapod._tcp`) for discovery on STA network

## Non-Goals (for now)
- WPA3 transition (can revisit after stabilization)
- Mesh networking
- Captive portal based firmware update (lower priority until core locomotion stable)

## Migration Checklist to AP+STA
- [ ] Implement NVS credential store module
- [ ] Simple HTTP portal for credential entry
- [ ] Add handshake/auth layer to TCP control channel (optional gating)
- [ ] Policy for AP disable (config flag)
- [ ] OTA integration using esp_https_ota

---
This document will evolve; keep it updated as connectivity features progress.

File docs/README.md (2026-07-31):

# Hexapod Documentation

## Structure

```
docs/
  common/          — controller input drivers, RPC, WiFi, config platform
  architecture/    — system and hardware architecture
  development/     — development setup and workflow
  plans/           — project-wide TODO and forward-looking plans
```

---

## Common

These docs describe subsystems that are shared across firmware: controller
input drivers, the RPC system, WiFi and Bluetooth transports, and the configuration
platform.

### Configuration

- [common/configuration/CONFIGURATION_PERSISTENCE_DESIGN.md](common/configuration/CONFIGURATION_PERSISTENCE_DESIGN.md)
- [common/configuration/CONFIG_MANAGER_NAMESPACE_TEMPLATE.md](common/configuration/CONFIG_MANAGER_NAMESPACE_TEMPLATE.md)
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

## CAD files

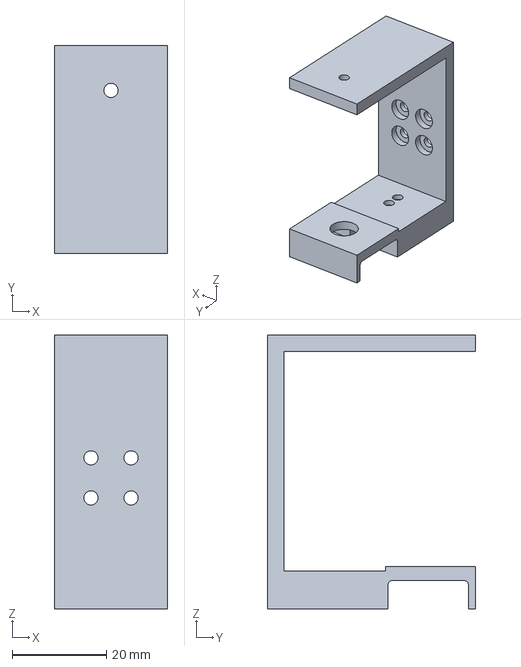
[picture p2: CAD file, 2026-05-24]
hardware/models/hexapod_v1.FCStd
24.0 x 44.0 x 58.0 mm

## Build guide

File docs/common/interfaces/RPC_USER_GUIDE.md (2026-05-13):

# Hexapod RPC User Guide

## Overview

The Hexapod firmware exposes a text-based RPC interface for runtime configuration and control ingress.

This guide is operational-only:
- how to connect
- how to send commands safely
- practical workflows for tuning and persistence

For authoritative protocol behavior (supported commands, framing, and semantics), see [RPC_SYSTEM_DESIGN.md](RPC_SYSTEM_DESIGN.md).

## Transport Setup

### Bluetooth Classic SPP

1. Power on the robot.
2. Pair with device name `HEXAPOD_XXXXXX` (MAC suffix).
3. Use PIN `1234` unless changed.
4. Open the outgoing virtual COM port in your terminal.

Notes:
- One SPP client is supported at a time.
- Transport is a byte stream; send text commands terminated with newline.

### WiFi TCP

1. Connect to the robot AP.
2. Open a TCP connection to the configured listen port.
3. Send line-based text commands terminated with `\n` or `\r\n`.

Notes:
- One active TCP client session is supported at a time.

## Command Format

General form (refer to canonical contract for full command semantics):

```text
<command> [arg1] [arg2] ...
```

Examples:

```text
list namespaces
list system
get system emergency_stop_enabled
set system emergency_stop_enabled true
setpersist wifi tcp_listen_port 5555
save wifi
export system
```

High-rate controller ingress:

```text
set controller <ch0> <ch1> ... <ch31>
```

If fewer than 32 channel values are provided, missing channels are set to `0`.

Tip:
- Run `help` and `list namespaces` on the connected target to discover runtime-supported operations.

## Response Behavior

- Responses are CRLF-terminated text lines.
- Current implementation does not append a separate trailing `OK` line.
- Most commands return one line with either data or an `ERROR ...` message.
- `set controller ...` intentionally returns no response to avoid extra traffic.

Typical responses:

```text
namespaces: system, joint_cal, leg_geom, motion_lim, controller, wifi
emergency_stop_enabled=true
emergency_stop_enabled=true (persist)
save system: OK
ERROR set emergency_stop_enabled
```

## Limits and Validation

- Maximum input line length is 255 characters in the RPC parser.
- Overlong lines return `ERROR line too long`.
- Parameters are type-checked and range-validated by config manager descriptors.

## Practical Workflows

### Read and tune one parameter

```text
get motion_lim max_velocity_coxa
set motion_lim max_velocity_coxa 4.5
setpersist motion_lim max_velocity_coxa 4.5
```

### Tune gait trajectory parameters

```text
list gait
get gait cycle_time_s
get gait step_length_m
set gait step_length_m 0.09
setpersist gait max_yaw_per_cycle_rad 0.35
setpersist gait turn_direction 1.0
save gait
```

Notes:
- `cycle_time_s`, `step_length_m`, and `clearance_height_m` control high-level gait timing and swing shape.
- `y_range_m`, `z_min_m`, and `z_max_m` control pose-to-foot target mapping.
- `max_yaw_per_cycle_rad` and `turn_direction` control turning behavior.

### Tune controller stick deadband

```text
get controller stick_deadband
set controller stick_deadband 0.03
setpersist controller stick_deadband 0.03
save controller
```

Notes:
- `stick_deadband` is clamped and validated in range `0.0 .. 0.3`.
- Lower values increase stick sensitivity near center; higher values suppress noise.

### Tune controller failsafe command profile

```text
list controller
get controller failsafe_enable
set controller failsafe_enable 1
set controller failsafe_gait 2
set controller failsafe_step_scale 0.4
setpersist controller failsafe_vx 0.0
setpersist controller failsafe_wz 0.0
setpersist controller failsafe_z_target -0.1
setpersist controller failsafe_pose_mode 1
save controller
```

Notes:
- Failsafe profile is applied when controller input is unavailable.
- `failsafe_gait` values are `0=wave`, `1=ripple`, `2=tripod`.
- Float constraints: `failsafe_vx`, `failsafe_wz`, `failsafe_z_target`, `failsafe_y_offset` in `-1.0 .. 1.0`, `failsafe_step_scale` in `0.0 .. 1.0`.

### Save all dirty namespaces

```text
save
```

### Factory reset

```text
factory-reset
```

This erases robot configuration namespaces and reloads defaults. Use with care.

## Troubleshooting

- No response:
  - verify transport connection (Bluetooth COM/TCP socket)
  - verify newline-terminated commands
- `unknown: <cmd>`:
  - command not implemented
- `set: not found` or `get: not found`:
  - wrong namespace or parameter name
- frequent disconnects:
  - check WiFi/Bluetooth link quality and timeout settings

## Related Documentation

- See [RPC_SYSTEM_DESIGN.md](RPC_SYSTEM_DESIGN.md) for the canonical RPC command contract.
- See [WIFI_TCP_PROTOCOL.md](WIFI_TCP_PROTOCOL.md) and [BLUETOOTH_CLASSIC_PROTOCOL.md](BLUETOOTH_CLASSIC_PROTOCOL.md) for transport-specific context.

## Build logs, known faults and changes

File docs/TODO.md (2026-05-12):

# Hexapod Robot Project TODO List

## 🎯 Project Vision & New Goals

### Hardware Improvements
- [ ] **Touch sensors at each leg**
  - Research suitable force/pressure sensors for leg-ground contact detection
  - Design mounting system for sensors on leg tips
  - Implement sensor reading and processing
  - Integrate touch feedback into gait control system

- [ ] **Electronics & Power System Upgrade**
  - Replace/improve current power board to ESP32 connectors
  - Design more reliable electrical connections
  - Consider PCB design for better signal integrity
  - Implement proper power management and distribution

- [ ] **IMU Integration for Terrain Leveling**
  - Add IMU sensor (accelerometer + gyroscope)
  - Implement body position/orientation estimation
  - Develop terrain leveling algorithms
  - Integrate IMU feedback into whole body control system

### Controller Systems
- [ ] **FlySky Controller Reconnection**
  - Debug signal stability issues caused by electronics interference
  - Implement proper signal filtering/shielding
  - Test and validate reliable communication
  - Add failsafe mechanisms

- [ ] **ESP-NOW Controller Implementation**
  - Design ESP-NOW communication protocol
  - Implement controller device (separate ESP32)
  - Add wireless communication handling
  - Create user interface for ESP-NOW controller

### Vision & Processing
- [ ] **Jetson Nano Integration**
  - Add Jetson Nano compute module to the system
  - Design mounting and power solution
  - Implement dual camera system
  - Develop computer vision capabilities
  - Create communication bridge between ESP32 and Jetson Nano

### Configuration & Tuning Portal
- [ ] **Hexapod Configurator (Betaflight-inspired)**
  - Design web-based configuration portal for robot tuning
  - Implement RPC-like communication protocol between configurator and ESP32
  - Create real-time parameter adjustment interface
  - Add live telemetry and monitoring capabilities
  - Implement configuration backup/restore functionality

---

## 🔧 Existing Code TODOs

### Configuration & Storage
- [x] **NVS Storage Foundation** (`hex_config_manager`, `hex_motion_limits`, `robot_config`)
  - Implemented namespace-based NVS persistence for `system`, `joint_cal`, `leg_geom`, and `motion_lim`
  - Implemented boot-time load/default/migration pipeline in config manager
  - Implemented KPP runtime consumption of `motion_lim` during `kpp_init` with fail-fast behavior

- [ ] **NVS Scope Expansion**
  - Extend persisted namespaces to `servo_map`, `controller`, `gait`, `debug`, and `wifi` as needed
  - Add explicit coverage tracking for remaining parameter schemas

- [ ] **Per-leg Configuration** (`robot_config.c`)
  - [x] Replace geometry/mount/stance hardcoded defaults with storage-loaded values when `leg_geom` is loaded
  - Consider per-leg geometry differences (mirrors, tolerances)
  - [ ] Remove remaining fallback paths once strict source-of-truth policy is finalized (`joint_cal` still has fallback defaults)

### Motion Control System
- [ ] **Advanced Motion Modes** (`kpp_system.h`)
  - Add MOTION_MODE_FAST for quick reactions
  - Add MOTION_MODE_EMERGENCY for fall recovery
  - Add mode_transition_time for multi-mode support
  - Implement fast mode limits
  - Implement emergency mode limits

- [ ] **Swing Trajectory Improvements** (`swing_trajectory.c`, `swing_trajectory.h`)
  - Make swing trajectory parameters configurable via Kconfig or runtime config
  - Make max turn angle configurable (currently hardcoded to 0.4 rad)
  - Make turn direction configurable
  - Add simple body roll/pitch offsets when pose_mode is active
  - Add yaw (wz) coupling to bias per-leg x/y for turning
  - Consider exposing trajectory parameters via config or calibration struct
  - Add C1/C2-continuous swing/stance blending to reduce velocity/acceleration discontinuities at phase boundaries
  - Add minimum-jerk or quintic foot trajectory mode for smoother liftoff/touchdown
  - Add configurable easing windows around liftoff/touchdown events

- [ ] **Gait Scheduler Enhancements** (`gait_scheduler.c`)
  - Consider separate forward/turning components and modulate phase rate
  - Replace current groupings with well-defined groupings and exact phase windows per gait
  - Add commanded-speed slew limiting so phase/frequency changes are gradual
  - Add gait transition blending (tripod/ripple/wave) to avoid abrupt group switching

### Control & Safety
- [ ] **Error Handling & Safety** (`whole_body_control.c`)
  - Add error signaling so robot_control can engage a safe stop
  - Implement comprehensive safety mechanisms
  - Add system health monitoring
  - Add arming checks (controller link valid, config loaded, telemetry channel healthy, basic power checks)
  - Add parameter-change safe-apply flow with timeout revert for risky live tuning updates

- [ ] **Controller Configuration** (`controller.c`)
  - Make DEAD_BAND configurable via Kconfig or runtime configuration
  - Add controller parameter tuning interfaces

### Future Sensor Integration
- [ ] **Coordinate Frame Transformations** (`kpp_config.h`)
  - Add coordinate frame transformation parameters
  - Implement sensor fusion framework

- [ ] **Sensor Fusion Parameters** (`kpp_config.h`)
  - Design sensor fusion architecture for IMU/force sensors
  - Implement sensor data processing pipeline
  - Add sensor calibration procedures

---

## 🖥️ Hexapod Configurator Portal (Betaflight-inspired)

### Core Infrastructure
- [ ] **Communication Protocol**
  - Design JSON-RPC or MessagePack-based protocol for ESP32 ↔ Configurator
  - Implement WebSocket connection for real-time communication
  - Add command/response handling with error codes
  - Create parameter read/write API endpoints
  - Implement telemetry streaming protocol
  - Split channels into command/control plane and telemetry plane to avoid tuning latency under load
  - Add topic-based telemetry subscription with configurable publish rates

- [ ] **Web Application Framework**
  - Create React/Vue.js based configurator interface
  - Design responsive UI for desktop and tablet use
  - Implement WebSocket client for ESP32 communication
  - Add configuration state management
  - Create reusable UI components for parameter tuning

### Configuration Pages & Features

#### 🦿 **Leg Configuration Tab**
- [ ] Individual leg parameter tuning
  - Per-leg servo angle offsets and limits
  - Leg geometry parameters (coxa, femur, tibia lengths)
  - Servo direction and calibration settings
  - Real-time leg position visualization (3D model)
  - "Test Leg Movement" controls for each leg

#### ⚙️ **Motion Control Tab**
- [ ] Gait pattern configuration
  - Gait type selection (tripod, wave, ripple, custom)
  - Step height, length, and timing parameters
  - Swing trajectory curve parameters
  - Body height and stance width settings
  - Real-time gait visualization

#### 🎮 **Controller Settings Tab**
- [ ] Input device configuration
  - FlySky controller channel mapping and calibration
  - ESP-NOW controller pairing and setup
  - Dead zones and sensitivity curves
  - Control mode switching (manual/autonomous)
  - Input signal monitoring and diagnostics

#### 🧭 **Sensors & IMU Tab**
- [ ] Sensor calibration and monitoring
  - IMU calibration wizard (accelerometer, gyroscope)
  - Touch sensor threshold settings per leg
  - Real-time sensor data visualization
  - Terrain leveling algorithm parameters
  - Sensor fusion weight settings

#### 🔧 **System Parameters Tab**
- [ ] Core system configuration
  - KPP motion limits (velocity, acceleration, jerk)
  - Safety parameters and emergency stops
  - Power management settings
  - Debug logging levels
  - System health monitoring

#### 📊 **Telemetry & Monitoring Tab**
- [ ] Real-time robot status
  - Live 3D robot visualization showing current pose
  - Servo positions and load monitoring
  - Battery voltage and current consumption
  - System temperature monitoring
  - Error logs and diagnostic information
  - Per-joint plots: commanded vs limited angle/velocity/acceleration
  - Gait plots: phase, support/swing state, foot target XYZ per leg
  - Control-loop timing charts (dt jitter, loop overrun counters)

#### 💾 **Configuration Management Tab**
- [ ] Profile and backup management
  - Save/load configuration profiles
  - Export/import settings to/from files
  - Factory reset functionality
  - Configuration versioning and diff viewing
  - Automatic backup before major changes

### Advanced Features
- [ ] **Live Tuning & Testing**
  - Real-time parameter adjustment with immediate effect
  - "Safe Mode" with automatic revert after timeout
  - Parameter validation and bounds checking
  - Undo/redo functionality for parameter changes
  - Batch parameter updates

- [ ] **Calibration Wizards**
  - Automated servo calibration sequence
  - IMU calibration step-by-step guide
  - Leg geometry measurement assistant
  - Gait optimization wizard
  - Touch sensor threshold auto-calibration

- [ ] **Diagnostic Tools**
  - Servo health check and performance testing
  - Communication link quality monitoring
  - System performance profiling
  - Error code lookup and troubleshooting guide
  - Log file viewer and analysis
  - Blackbox-style ring buffer capture with event markers (failsafe, IK error, timeout)
  - Export log bundles for offline plotting/comparison between tuning sessions
  - Pre/post event capture windows for fault analysis

### ESP32 Firmware Support
- [ ] **Parameter Storage System**
  - Extend NVS storage to support all configurable parameters
  - Implement parameter validation and bounds checking
  - Add parameter change notification system
  - Create parameter schema/metadata system
  - Implement atomic parameter updates

- [ ] **Web Server & API**
  - Implement HTTP server for configurator hosting
  - Add WebSocket server for real-time communication
  - Create REST API for parameter access
  - Implement file upload/download for configurations
  - Add OTA update support through configurator

- [ ] **Telemetry System**
  - Real-time data streaming to configurator
  - Configurable telemetry rates and data selection
  - Data logging to SD card or flash memory
  - Remote logging capabilities
  - Performance metrics collection
  - Binary telemetry encoding (MessagePack/CBOR) to reduce bandwidth and latency vs text logs
  - Per-topic rate limiting and backpressure handling to protect control-loop timing
  - Runtime telemetry on/off and topic filtering without reboot

---

## 📋 Implementation Priority

### Phase 1: Foundation (High Priority)
1. FlySky controller debugging and reconnection
2. Electronics/connector improvements
3. Expand NVS coverage for remaining namespaces (foundation is complete)
4. Error handling and safety mechanisms
5. **Basic configurator infrastructure** (communication protocol, web framework)
6. **High-rate WiFi telemetry path** (non-serial observability for tuning)

### Phase 2: Enhanced Control & Configuration (Medium Priority)
1. **Core configurator pages** (Leg Config, Motion Control, System Parameters)
2. IMU integration and terrain leveling
3. Touch sensors implementation
4. Advanced motion modes (Fast/Emergency)
5. Swing trajectory improvements
6. **Configuration management and calibration wizards**
7. **Gait transition smoothing + phase/frequency slew limiting**

### Phase 3: Advanced Features (Lower Priority)
1. **Advanced configurator features** (telemetry, diagnostics, live tuning)
2. ESP-NOW controller development
3. Jetson Nano integration
4. Dual camera system
5. Computer vision capabilities
6. Advanced sensor fusion
7. **Blackbox-style event logging and offline analysis workflow**

---

## 📝 Notes
- Current system has comprehensive KPP (Kinematic Pose Position) implementation
- Debug infrastructure is in place for development and tuning
- Motion limiting and safety systems are partially implemented
- FlySky controller was previously working but needs debugging for signal stability

---

*Last updated: May 12, 2026*

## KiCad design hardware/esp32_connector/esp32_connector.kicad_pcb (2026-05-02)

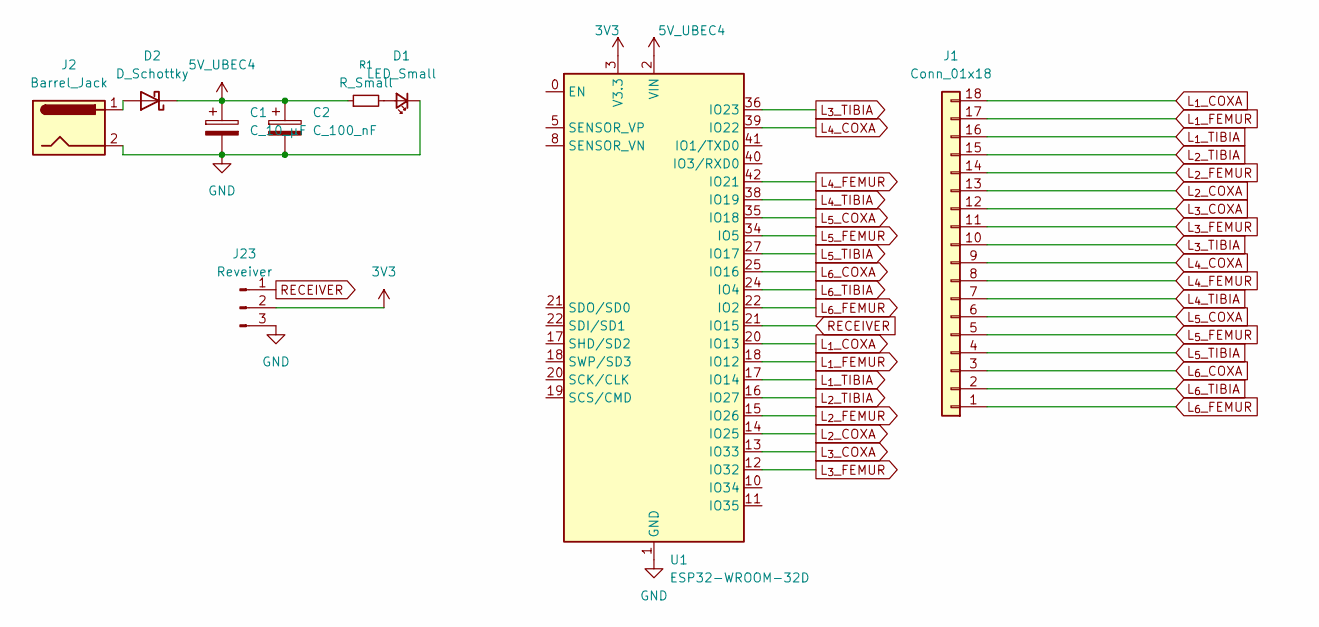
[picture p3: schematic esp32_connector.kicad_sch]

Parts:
C1: C_10_µF; C_1206_3216Metric
C2: C_100_nF; C_0805_2012Metric
D1: LED_Small; LED_0805_2012Metric
D2: D_Schottky; D_SOD-123
J1: Conn_01x18; TE_1-84952-8_1x18-1MP_P1.0mm_Horizontal
J2: Barrel_Jack; TerminalBlock_Phoenix_MKDS-1,5-2_1x02_P5.00mm_Horizontal
J23: Reveiver; PinHeader_1x03_P2.54mm_Vertical
R1: R_Small; R_0805_2012Metric
U1: ESP32-WROOM-32D; ESP32_Dev_Board

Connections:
3V3: J23.2, U1.3 (V3.3)
5V_UBEC4: C1.1, C2.1, D2.1 (K), R1.1, U1.2 (VIN)
L_{1}_COXA: J1.18, U1.20 (IO13)
L_{1}_FEMUR: J1.17, U1.18 (IO12)
L_{1}_TIBIA: J1.16, U1.17 (IO14)
L_{2}_COXA: J1.13, U1.14 (IO25)
L_{2}_TIBIA: J1.15, U1.16 (IO27)
L_{3}_COXA: J1.12, U1.13 (IO33)
L_{3}_FEMUR: J1.11, U1.12 (IO32)
L_{3}_TIBIA: J1.10, U1.36 (IO23)
L_{4}_FEMUR: J1.8, U1.42 (IO21)
L_{5}_COXA: J1.6, U1.35 (IO18)
L_{5}_FEMUR: J1.5, U1.34 (IO5)
L_{5}_TIBIA: J1.4, U1.27 (IO17)
L_{6}_COXA: J1.3, U1.25 (IO16)
L_{6}_FEMUR: J1.1, U1.22 (IO2)
L_{6}_TIBIA: J1.2, U1.24 (IO4)
unnamed: D1.2 (A), R1.2
unnamed: D2.2 (A), J2.1
RECEIVER: J23.1, U1.21 (IO15)

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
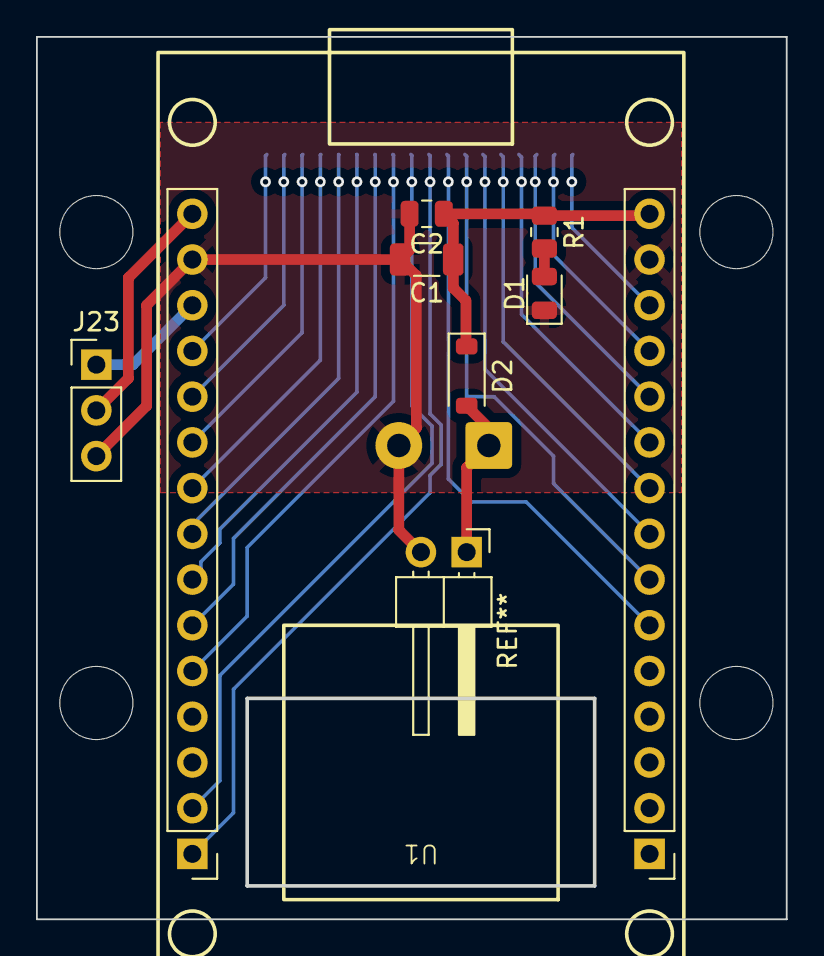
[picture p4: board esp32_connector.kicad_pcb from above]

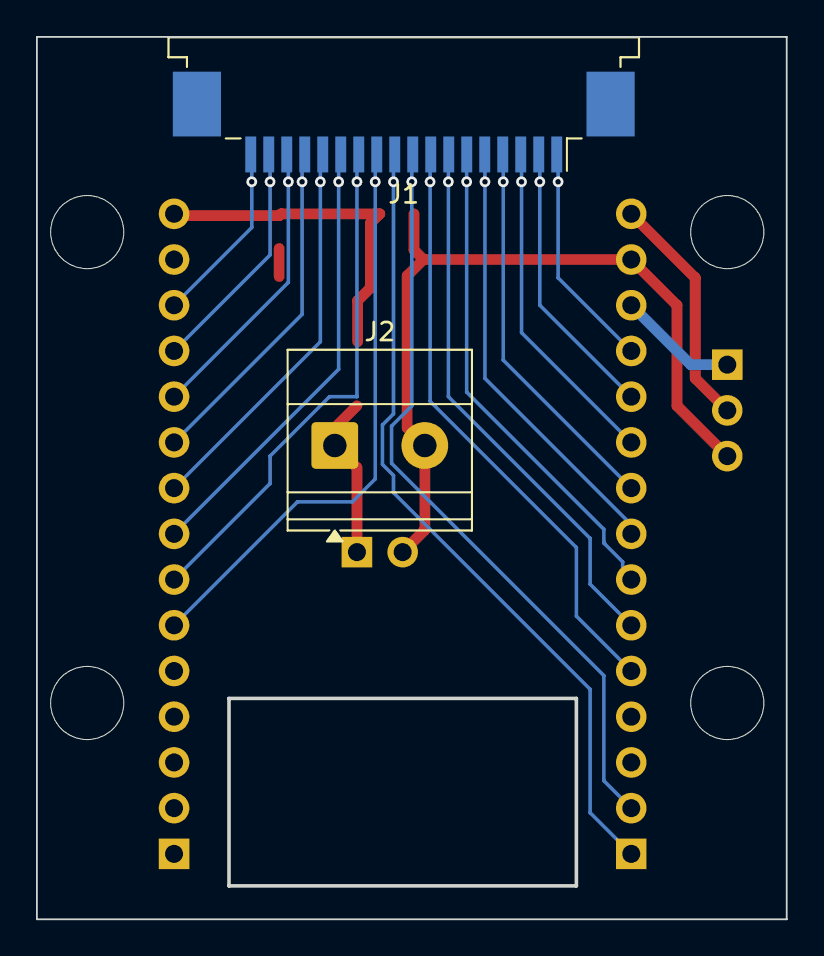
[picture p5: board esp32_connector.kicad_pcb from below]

Board: 2 copper layers, 41.7 x 49.0 mm, 9 parts (2 on the bottom side), 24 nets.

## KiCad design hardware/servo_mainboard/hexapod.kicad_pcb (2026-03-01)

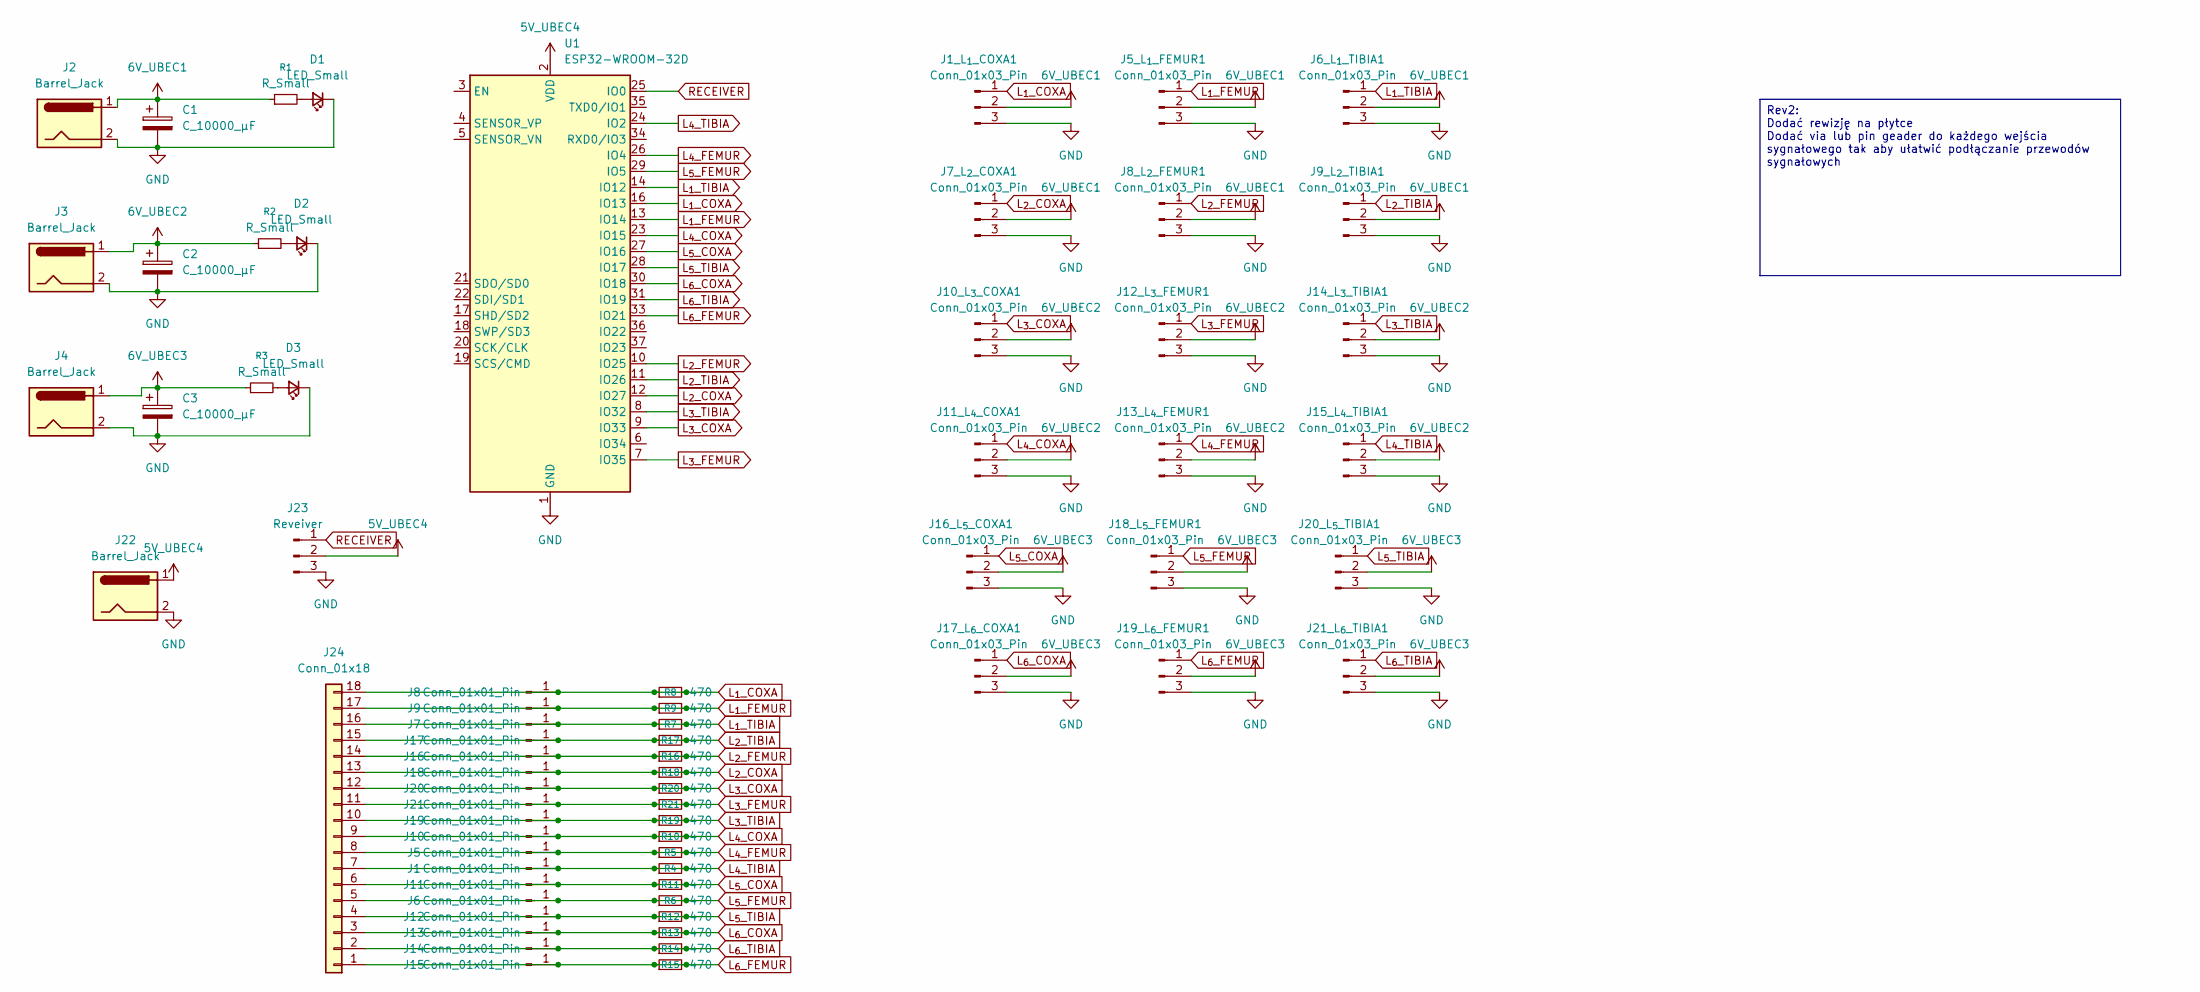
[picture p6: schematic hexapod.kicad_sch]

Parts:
C1, C2, C3: C_10000_µF; CP_Radial_D16.0mm_P7.50mm
D1, D2, D3: LED_Small; LED_0805_2012Metric
J1, J5, J6, J7, J8, J9, J10, J11, J12, J13, J14, J15, J16, J17, J18, J19, J20, J21: Conn_01x01_Pin; PinHeader_1x01_P2.54mm_Vertical
J1_L_{1}_COXA1, J5_L_{1}_FEMUR1, J6_L_{1}_TIBIA1, J10_L_{3}_COXA1, J11_L_{4}_COXA1, J12_L_{3}_FEMUR1, J13_L_{4}_FEMUR1, J14_L_{3}_TIBIA1, J15_L_{4}_TIBIA1, J17_L_{6}_COXA1, J19_L_{6}_FEMUR1, J21_L_{6}_TIBIA1: Conn_01x03_Pin; PinHeader_1x03_P2.54mm_Horizontal
J2, J3, J4, J22: Barrel_Jack; TerminalBlock_Phoenix_MKDS-1,5-2_1x02_P5.00mm_Horizontal
J7_L_{2}_COXA1, J8_L_{2}_FEMUR1, J9_L_{2}_TIBIA1, J16_L_{5}_COXA1, J18_L_{5}_FEMUR1, J20_L_{5}_TIBIA1: Conn_01x03_Pin; PinHeader_1x03_P2.54mm_Vertical
J23: Reveiver; PinHeader_1x03_P2.54mm_Vertical
J24: Conn_01x18; TE_1-84952-8_1x18-1MP_P1.0mm_Horizontal
R1, R2, R3: R_Small; R_0805_2012Metric
R4, R5, R6, R7, R8, R9, R10, R11, R12, R13, R14, R15, R16, R17, R18, R19, R20, R21: 470; R_0805_2012Metric_Pad1.20x1.40mm_HandSolder
U1: ESP32-WROOM-32D; ESP32_Dev_Board

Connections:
6V_UBEC1: C1.1, J1_L_{1}_COXA1.2, J2.1, J5_L_{1}_FEMUR1.2, J6_L_{1}_TIBIA1.2, J7_L_{2}_COXA1.2, J8_L_{2}_FEMUR1.2, J9_L_{2}_TIBIA1.2, R1.1
6V_UBEC2: C2.1, J3.1, J10_L_{3}_COXA1.2, J11_L_{4}_COXA1.2, J12_L_{3}_FEMUR1.2, J13_L_{4}_FEMUR1.2, J14_L_{3}_TIBIA1.2, J15_L_{4}_TIBIA1.2, R2.1
6V_UBEC3: C3.1, J4.1, J16_L_{5}_COXA1.2, J17_L_{6}_COXA1.2, J18_L_{5}_FEMUR1.2, J19_L_{6}_FEMUR1.2, J20_L_{5}_TIBIA1.2, J21_L_{6}_TIBIA1.2, R3.1
GND: C1.2, C2.2, C3.2, D1.1 (K), D2.1 (K), D3.1 (K), J1_L_{1}_COXA1.3, J2.2, J3.2, J4.2, J5_L_{1}_FEMUR1.3, J6_L_{1}_TIBIA1.3, J7_L_{2}_COXA1.3, J8_L_{2}_FEMUR1.3, J9_L_{2}_TIBIA1.3, J10_L_{3}_COXA1.3, J11_L_{4}_COXA1.3, J12_L_{3}_FEMUR1.3, J13_L_{4}_FEMUR1.3, J14_L_{3}_TIBIA1.3, J15_L_{4}_TIBIA1.3, J16_L_{5}_COXA1.3, J17_L_{6}_COXA1.3, J18_L_{5}_FEMUR1.3, J19_L_{6}_FEMUR1.3, J20_L_{5}_TIBIA1.3, J21_L_{6}_TIBIA1.3, J22.2, J23.3, U1.1 (GND), U1.15 (GND), U1.38 (GND), U1.39 (GND)
L_{1}_COXA: J1_L_{1}_COXA1.1, J8.1, J24.18, R8.1, R8.2, U1.16 (IO13)
L_{1}_FEMUR: J5_L_{1}_FEMUR1.1, J9.1, J24.17, R9.1, R9.2, U1.13 (IO14)
L_{1}_TIBIA: J6_L_{1}_TIBIA1.1, J7.1, J24.16, R7.1, R7.2, U1.14 (IO12)
L_{2}_COXA: J7_L_{2}_COXA1.1, J18.1, J24.13, R18.1, R18.2, U1.12 (IO27)
L_{2}_FEMUR: J8_L_{2}_FEMUR1.1, J16.1, J24.14, R16.1, R16.2, U1.10 (IO25)
L_{2}_TIBIA: J9_L_{2}_TIBIA1.1, J17.1, J24.15, R17.1, R17.2, U1.11 (IO26)
L_{3}_COXA: J10_L_{3}_COXA1.1, J20.1, J24.12, R20.1, R20.2, U1.9 (IO33)
L_{3}_FEMUR: J12_L_{3}_FEMUR1.1, J21.1, J24.11, R21.1, R21.2, U1.7 (IO35)
L_{3}_TIBIA: J14_L_{3}_TIBIA1.1, J19.1, J24.10, R19.1, R19.2, U1.8 (IO32)
L_{4}_COXA: J10.1, J11_L_{4}_COXA1.1, J24.9, R10.1, R10.2, U1.23 (IO15)
L_{4}_FEMUR: J5.1, J13_L_{4}_FEMUR1.1, J24.8, R5.1, R5.2, U1.26 (IO4)
L_{4}_TIBIA: J1.1, J15_L_{4}_TIBIA1.1, J24.7, R4.1, R4.2, U1.24 (IO2)
L_{5}_COXA: J11.1, J16_L_{5}_COXA1.1, J24.6, R11.1, R11.2, U1.27 (IO16)
L_{5}_FEMUR: J6.1, J18_L_{5}_FEMUR1.1, J24.5, R6.1, R6.2, U1.29 (IO5)
L_{5}_TIBIA: J12.1, J20_L_{5}_TIBIA1.1, J24.4, R12.1, R12.2, U1.28 (IO17)
L_{6}_COXA: J13.1, J17_L_{6}_COXA1.1, J24.3, R13.1, R13.2, U1.30 (IO18)
L_{6}_FEMUR: J15.1, J19_L_{6}_FEMUR1.1, J24.1, R15.1, R15.2, U1.33 (IO21)
L_{6}_TIBIA: J14.1, J21_L_{6}_TIBIA1.1, J24.2, R14.1, R14.2, U1.31 (IO19)
unnamed: D1.2 (A), R1.2
unnamed: D2.2 (A), R2.2
unnamed: D3.2 (A), R3.2
unnamed: J22.1, J23.2, U1.2 (VDD)
unnamed: J23.1, U1.25 (IO0)

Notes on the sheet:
Rev2: Dodać rewizję na płytce Dodać via lub pin geader do każdego wejścia sygnałowego tak aby ułatwić podłączanie przewodów sygnałowych

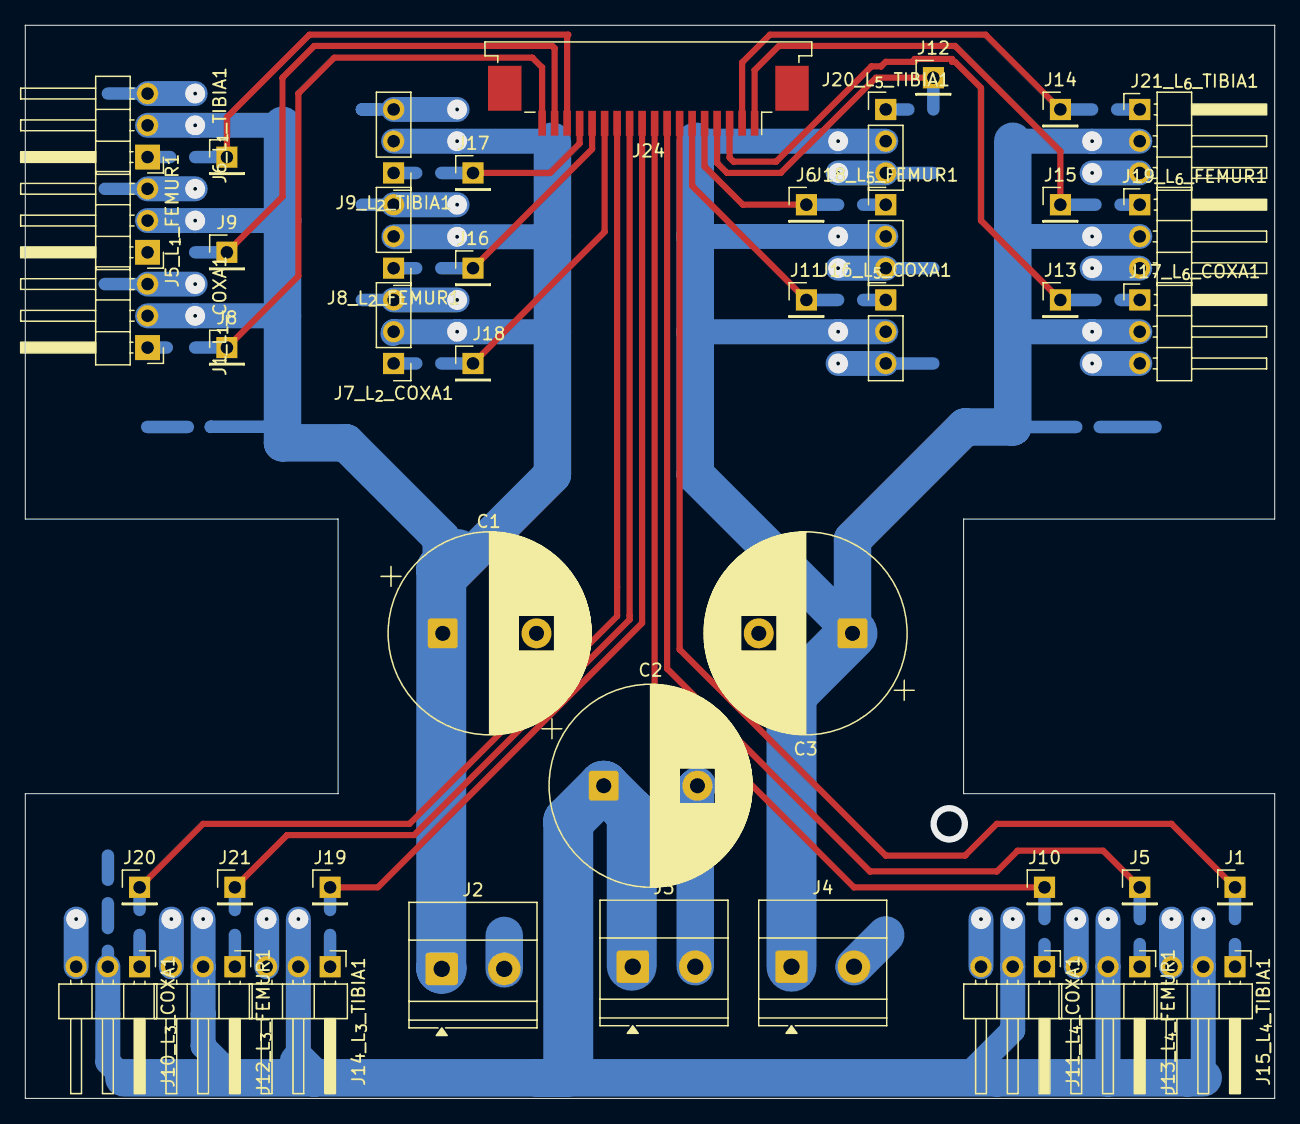
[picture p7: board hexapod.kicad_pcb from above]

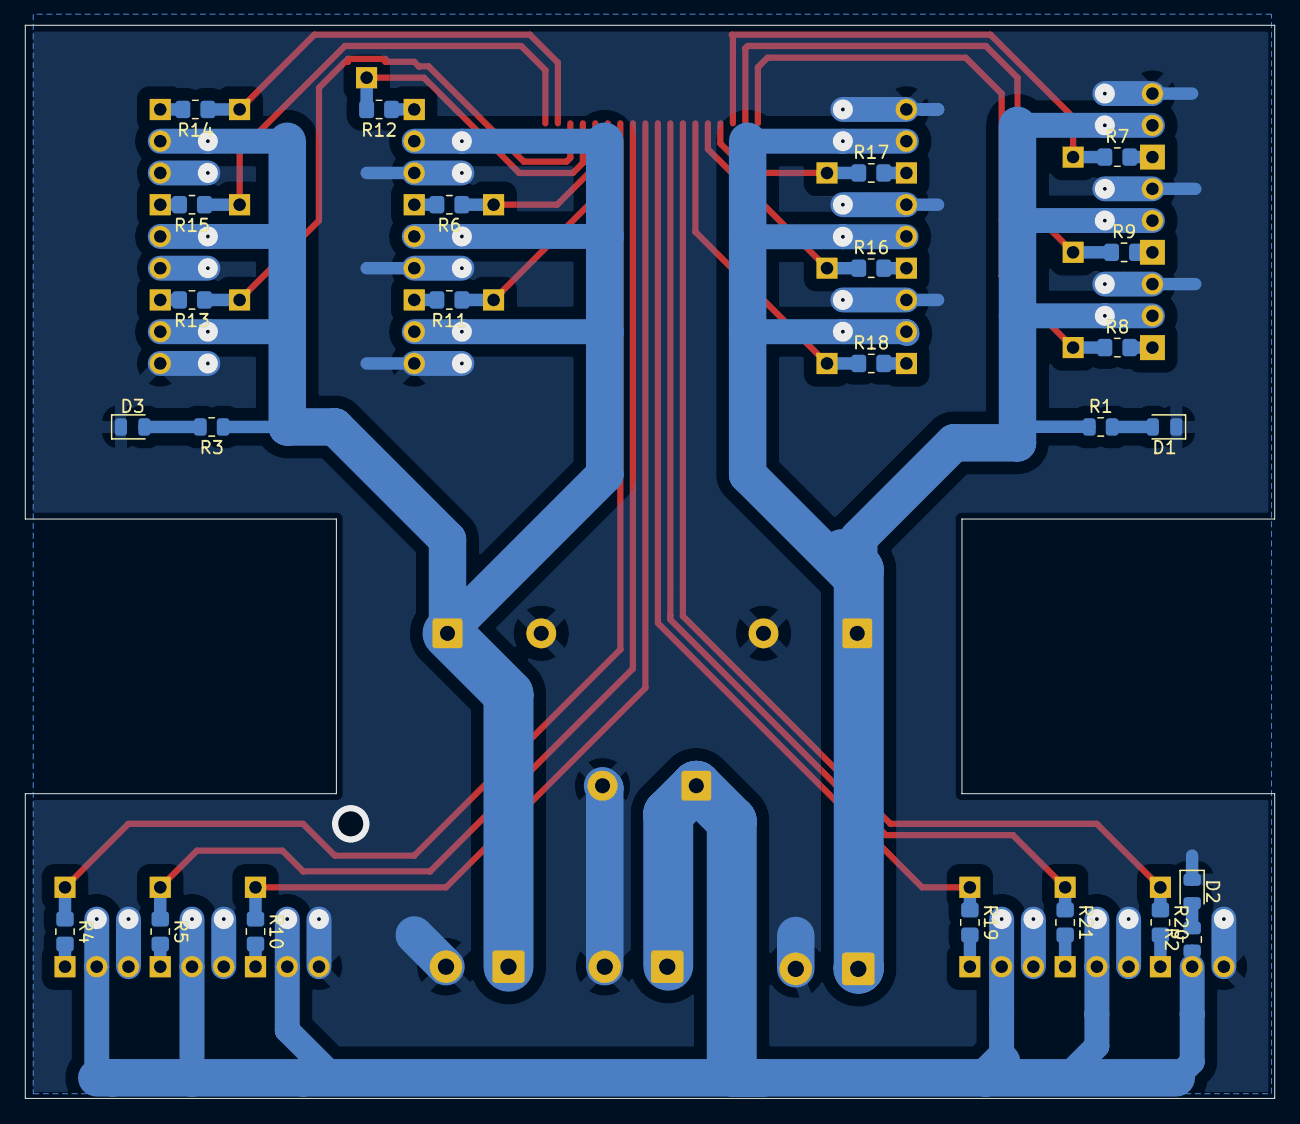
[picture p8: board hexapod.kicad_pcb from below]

Board: 2 copper layers, 99.9 x 85.9 mm, 67 parts (24 on the bottom side), 25 nets.

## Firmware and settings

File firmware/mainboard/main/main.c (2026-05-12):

/*
 *
 * License: Apache-2.0
 */

#include "esp_timer.h"
#include "freertos/FreeRTOS.h"
#include "freertos/task.h"
#include "esp_log.h"
#include "driver/mcpwm_prelude.h"
#include "leg.h"
#include <math.h>
#include "gait_scheduler.h"
#include "swing_trajectory.h"
#include "whole_body_control.h"
#include "robot_control.h"
#include "robot_config.h"
#include "user_command.h"
#include "controller.h"
#include "controller_flysky_ibus.h"
#include <string.h>
#include "wifi_ap.h"
#include "controller_bt_classic.h"
#include "controller_wifi_tcp.h"
#include "kpp_system.h"
#include "config_manager_runtime_api.h"
#include "config_ns_system_api.h"
#include "config_ns_controller_api.h"
#include "config_ns_wifi_api.h"
#include "config_ns_gait_api.h"
#include "rpc_commands.h"

static const char *TAG = "main";

// --- Gait Framework Main Loop ---
void gait_framework_main(void *arg)
{
    gait_scheduler_t scheduler;
    swing_trajectory_t trajectory;
    whole_body_cmd_t cmds;
    user_command_t ucmd; // current command
    user_command_t prev_cmd; // previous command for change detection
    memset(&ucmd, 0, sizeof(ucmd));
    memset(&prev_cmd, 0, sizeof(prev_cmd));

    // Initialize KPP (Kinematic Pose Position) system
    kinematic_state_t kpp_state;
    motion_limits_t motion_limits;
    ESP_ERROR_CHECK(kpp_init(&kpp_state, &motion_limits));
    ESP_LOGI(TAG, "KPP system initialized with motion limiting enabled");

    // Initialize gait framework modules
    const gait_config_t* gait_cfg = config_get_gait();
    if (!gait_cfg) {
        ESP_LOGE(TAG, "Gait namespace unavailable");
        return;
    }

    gait_scheduler_init(&scheduler, gait_cfg->cycle_time_s);
    swing_trajectory_init(&trajectory, gait_cfg->step_length_m, gait_cfg->clearance_height_m);
    trajectory.y_range_m = gait_cfg->y_range_m;
    trajectory.z_min_m = gait_cfg->z_min_m;
    trajectory.z_max_m = gait_cfg->z_max_m;
    trajectory.max_yaw_per_cycle_rad = gait_cfg->max_yaw_per_cycle_rad;
    trajectory.turn_direction = gait_cfg->turn_direction;

    const float dt = 0.01f; // 10ms loop
    while (1) {
        float time_start = esp_timer_get_time();
        // Copy current to previous then poll new
        prev_cmd = ucmd;
        user_command_poll(&ucmd);
        if (!controller_user_command_equal(&prev_cmd, &ucmd, 1e-2f)) {
            ESP_LOGI(TAG, "User command: vx=%.2f, wz=%.2f, z_target=%.2f, y_offset=%.2f gait=%d enable=%d pose=%d terrain=%d step_scale=%.2f",
                    ucmd.vx, ucmd.wz, ucmd.z_target, ucmd.y_offset, ucmd.gait, ucmd.enable, ucmd.pose_mode, ucmd.terrain_climb, ucmd.step_scale);
        }

        // Update gait scheduler (leg phases)
        gait_scheduler_update(&scheduler, dt, &ucmd);
        // Generate swing trajectories for legs using scheduler + command
        swing_trajectory_generate(&trajectory, &scheduler, &ucmd);
        // Compute joint commands from trajectories
        whole_body_control_compute(&trajectory, &cmds);
        
        // KPP: Apply motion limiting for smooth servo operation
        whole_body_cmd_t limited_cmds;
        kpp_apply_limits(&kpp_state, &motion_limits, &cmds, &limited_cmds, dt);
        
        // Send limited commands to robot
        robot_execute(&limited_cmds);
        
        // CRITICAL FIX: Update state estimation based on ORIGINAL commands, not limited ones
        // This breaks the feedback loop that was causing oscillations
        kpp_update_state(&kpp_state, &cmds, dt);  // Use original commands for state estimation
        
        float time_end = esp_timer_get_time();
        // Calculate how long to wait to maintain dt period
        float elapsed = (time_end - time_start) / 1000.0f;
        float wait_ms = (dt * 1000.0f) - elapsed;
        int wait_ticks = (int)(wait_ms / portTICK_PERIOD_MS);
        if (wait_ticks < 1) wait_ticks = 1; // Ensure at least 1 tick
        vTaskDelay(wait_ticks);
    }
}

void app_main(void)
{
    // Initialize configuration manager first
    ESP_LOGI(TAG, "Starting hexapod application...");
    esp_err_t err = config_manager_init();
    if (err != ESP_OK) {
        ESP_LOGE(TAG, "Failed to initialize configuration manager: %s", esp_err_to_name(err));
        return;
    }
    
    // Get system configuration
    const system_config_t* sys_config = config_get_system();
    ESP_LOGI(TAG, "System config loaded: robot_id=%s, robot_name=%s", 
             sys_config->robot_id, sys_config->robot_name);
    ESP_LOGI(TAG, "Safety settings: emergency_stop=%s, voltage_min=%.2fV", 
             sys_config->emergency_stop_enabled ? "enabled" : "disabled",
             sys_config->safety_voltage_min);
    
    // Joint calibration system is now active and will be used by robot_control
    ESP_LOGI(TAG, "Joint calibration configuration loaded and ready for robot control");
    
    // Apply startup delay from configuration
    if (sys_config->startup_delay_ms > 0) {
        ESP_LOGI(TAG, "Applying startup delay: %lu ms", (unsigned long)sys_config->startup_delay_ms);
        vTaskDelay(pdMS_TO_TICKS(sys_config->startup_delay_ms));
    }
    
    // Initialize RPC system
    rpc_init();

    // Load WiFi namespace-backed options for AP and TCP controller transport.
    const wifi_config_namespace_t* wifi_ns_cfg = config_get_wifi();
    if (!wifi_ns_cfg) {
        ESP_LOGE(TAG, "WiFi namespace unavailable");
        return;
    }

    wifi_ap_options_t ap_opts = {
        .mode = (wifi_ap_ssid_mode_e)wifi_ns_cfg->ap_ssid_mode,
        .fixed_prefix = wifi_ns_cfg->ap_fixed_prefix,
        .fixed_ssid = wifi_ns_cfg->ap_fixed_ssid,
        .password = wifi_ns_cfg->ap_password,
        .channel = (uint8_t)wifi_ns_cfg->ap_channel,
        .max_clients = (uint8_t)wifi_ns_cfg->ap_max_clients,
    };
    
    // Bring up WiFi AP early so that network-based controller drivers or diagnostics
    // can connect even if later initialization stalls.
    if (!wifi_ap_init_with_options(&ap_opts)) {
        ESP_LOGE(TAG, "Failed to initialize WiFi AP from namespace configuration");
        return;
    }
    
    // Initialize robot configuration (namespace-backed; fail fast on invalid state)
    err = robot_config_init_default();
    if (err != ESP_OK) {
        ESP_LOGE(TAG, "Failed to initialize robot configuration: %s", esp_err_to_name(err));
        return;
    }
    
    // Initialize the primary controller from configuration namespaces.
    const controller_config_namespace_t* controller_cfg = config_get_controller();
    if (!controller_cfg) {
        ESP_LOGE(TAG, "Controller namespace unavailable");
        return;
    }

    controller_config_t ctrl_cfg = {
        .driver_type = controller_cfg->driver_type,
        .task_stack = (int)controller_cfg->task_stack,
        .task_prio = (int)controller_cfg->task_priority,
        .driver_cfg = NULL,
        .driver_cfg_size = 0,
    };

    // Assign driver-specific configuration if needed
    controller_flysky_ibus_cfg_t flysky_cfg;
    controller_wifi_tcp_cfg_t wifi_tcp_cfg;
    if (ctrl_cfg.driver_type == CONTROLLER_DRIVER_FLYSKY_IBUS) {
        flysky_cfg.uart_port = controller_cfg->flysky_uart_port;
        flysky_cfg.tx_gpio = controller_cfg->flysky_tx_gpio;
        flysky_cfg.rx_gpio = controller_cfg->flysky_rx_gpio;
        flysky_cfg.rts_gpio = controller_cfg->flysky_rts_gpio;
        flysky_cfg.cts_gpio = controller_cfg->flysky_cts_gpio;
        flysky_cfg.baud_rate = controller_cfg->flysky_baud_rate;
        ctrl_cfg.driver_cfg = &flysky_cfg;
        ctrl_cfg.driver_cfg_size = sizeof(flysky_cfg);
    } else if (ctrl_cfg.driver_type == CONTROLLER_DRIVER_WIFI_TCP) {
        wifi_tcp_cfg.listen_port = (uint16_t)wifi_ns_cfg->tcp_listen_port;
        wifi_tcp_cfg.connection_timeout_ms = (uint16_t)wifi_ns_cfg->tcp_connection_timeout_ms;
        ctrl_cfg.driver_cfg = &wifi_tcp_cfg;
        ctrl_cfg.driver_cfg_size = sizeof(wifi_tcp_cfg);
    }
    
    controller_init(&ctrl_cfg);

    // ALWAYS initialize WiFi TCP controller for RPC commands (separate from primary controller)
    // This provides network-based diagnostics and control regardless of primary controller type
    if (ctrl_cfg.driver_type != CONTROLLER_DRIVER_WIFI_TCP) {
        ESP_LOGI(TAG, "Initializing WiFi TCP controller as secondary RPC interface");
        controller_wifi_tcp_cfg_t wifi_rpc_cfg = {
            .listen_port = (uint16_t)wifi_ns_cfg->tcp_listen_port,
            .connection_timeout_ms = (uint16_t)wifi_ns_cfg->tcp_connection_timeout_ms,
        };
        controller_config_t wifi_ctrl_cfg = {
            .driver_type = CONTROLLER_DRIVER_WIFI_TCP,
            .task_stack = controller_cfg->task_stack, // Use same stack size as primary controller
            .task_prio = 8,  // Lower priority than primary controller
            .driver_cfg = &wifi_rpc_cfg,
            .driver_cfg_size = sizeof(wifi_rpc_cfg),
        };
        controller_driver_init_wifi_tcp(&wifi_ctrl_cfg);
    }
    
    gait_framework_main(NULL);
}

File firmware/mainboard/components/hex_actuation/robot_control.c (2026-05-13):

#include "robot_control.h"
#include "esp_log.h"
#include "esp_check.h"
#include "robot_config.h"
#include "driver/mcpwm_prelude.h"
#include "driver/ledc.h"
#include <math.h>
#ifndef M_PI
#define M_PI 3.14159265358979323846
#endif

static const char *TAG_RC = "robot_control";

// We will mix MCPWM (legs 0,1,4,5) and LEDC (legs 2,3) to reach 18 servos on classic ESP32.
// LEDC provides 16 channels total; we only need 6 of them here. We allocate a single LEDC timer
// configured for 50 Hz (20 ms) with 15-bit resolution giving ~0.61 us per step.
// Coexistence notes:
// - MCPWM and LEDC are independent peripherals; using both simultaneously is supported.
// - Each has its own hardware timer resources; there is no contention besides GPIO matrix routing.
// - Ensure chosen GPIOs are not reused elsewhere. Calibration and angle->pulse mapping is shared.
// - MCPWM yields exact microsecond compare logic; LEDC duty resolution here (~0.61us) is adequate for hobby servos.
// - Total capacity now: MCPWM up to 12 (2 groups * 3 operators * 2 generators) + LEDC 6 (channels 0..5) = 18.

typedef enum {
    SERVO_DRV_NONE = 0,
    SERVO_DRV_MCPWM,
    SERVO_DRV_LEDC,
} servo_driver_t;

#define SERVO_LEDC_TIMER          LEDC_TIMER_0
#define SERVO_LEDC_SPEED_MODE     LEDC_LOW_SPEED_MODE
#define SERVO_LEDC_RES_BITS       LEDC_TIMER_15_BIT
#define SERVO_LEDC_FREQUENCY_HZ   50

// Reserve a contiguous block of LEDC channels for legs 2 & 3 (6 joints: coxa,femur,tibia x2)
#define SERVO_LEDC_BASE_CHANNEL   LEDC_CHANNEL_0

static bool s_ledc_timer_inited = false;

// Simple MCPWM context per servo channel (leg,joint)
typedef struct {
    bool inited;
    bool disabled; // set true if resource allocation fails; skip updates
    int group_id;
    int gpio;
    servo_driver_t driver; // which backend drives this channel
    mcpwm_oper_handle_t oper;
    mcpwm_cmpr_handle_t cmpr;
    mcpwm_gen_handle_t gen;
    ledc_channel_t ledc_chan; // valid if driver == SERVO_DRV_LEDC
} pwm_chan_t;

static pwm_chan_t g_pwm[NUM_LEGS][3];

// Decide whether a given (leg,joint) should use LEDC based on configuration.
static inline bool use_ledc_for_joint(int leg_index, leg_servo_t joint) {
    return robot_config_get_servo_driver(leg_index, joint) == 1; // 1 -> LEDC per config
}

// Map (leg,joint) to a LEDC channel index starting at SERVO_LEDC_BASE_CHANNEL.
// Leg 2 joints 0..2 -> channels 0..2, Leg 3 joints 0..2 -> channels 3..5
// Build a compact channel index for all configured LEDC joints (lazy). Max expected 6 here.
static int s_ledc_channel_lut[NUM_LEGS][3]; // -1 if not LEDC, else compact index
static int s_ledc_lut_built = 0;
static void build_ledc_lut(void) {
    if (s_ledc_lut_built) return;
    for (int i=0;i<NUM_LEGS;++i) for (int j=0;j<3;++j) s_ledc_channel_lut[i][j] = -1;
    int next = 0;
    for (int i=0;i<NUM_LEGS;++i) {
        for (int j=0;j<3;++j) {
            if (robot_config_get_servo_driver(i,(leg_servo_t)j)==1) {
                s_ledc_channel_lut[i][j] = next++;
            }
        }
    }
    s_ledc_lut_built = 1;
}
static inline ledc_channel_t map_to_ledc_channel(int leg_index, leg_servo_t joint) {
    build_ledc_lut();
    int idx = s_ledc_channel_lut[leg_index][(int)joint];
    if (idx < 0) idx = 0; // fallback (should not happen if caller checked)
    return (ledc_channel_t)(SERVO_LEDC_BASE_CHANNEL + idx);
}

static esp_err_t ensure_ledc_timer_inited(void) {
    if (s_ledc_timer_inited) return ESP_OK;
    ledc_timer_config_t tcfg = {
        .speed_mode       = SERVO_LEDC_SPEED_MODE,
        .duty_resolution  = SERVO_LEDC_RES_BITS,
        .timer_num        = SERVO_LEDC_TIMER,
        .freq_hz          = SERVO_LEDC_FREQUENCY_HZ,
        .clk_cfg          = LEDC_AUTO_CLK,
    };
    esp_err_t err = ledc_timer_config(&tcfg);
    if (err == ESP_OK) {
        s_ledc_timer_inited = true;
        ESP_LOGI(TAG_RC, "Initialized shared LEDC timer (freq=%dHz, res=%d bits)", SERVO_LEDC_FREQUENCY_HZ, SERVO_LEDC_RES_BITS);
    } else {
        ESP_LOGE(TAG_RC, "Failed to init LEDC timer (%s)", esp_err_to_name(err));
    }
    return err;
}

// One shared timer per MCPWM group to avoid exhausting group timers
#define MAX_MCPWM_GROUPS 2 /* adjust if your target has more groups */
typedef struct {
    bool inited;
    mcpwm_timer_handle_t timer;
} group_timer_t;
static group_timer_t s_group_timers[MAX_MCPWM_GROUPS];

// Pool a small number of operators per group, each with up to two generators (A/B)
#define MAX_OPERATORS_PER_GROUP 3 // ESP32 classic has up to 3 operators per group
typedef struct {
    bool inited;
    mcpwm_oper_handle_t oper;
    int used_generators; // 0..2
} group_operator_t;
static group_operator_t s_group_op_pool[MAX_MCPWM_GROUPS][MAX_OPERATORS_PER_GROUP];

// Acquire an operator in the given group that still has a free generator slot
static esp_err_t acquire_operator_with_free_gen(int group, mcpwm_oper_handle_t *out_oper) {
    if (group < 0 || group >= MAX_MCPWM_GROUPS) return ESP_ERR_INVALID_ARG;
    // Try reuse first
    for (int i = 0; i < MAX_OPERATORS_PER_GROUP; ++i) {
        if (s_group_op_pool[group][i].inited && s_group_op_pool[group][i].used_generators < 2) {
            *out_oper = s_group_op_pool[group][i].oper;
            s_group_op_pool[group][i].used_generators++;
            ESP_LOGI(TAG_RC, "Reusing MCPWM operator %d in group %d (generators now %d)", i, group, s_group_op_pool[group][i].used_generators);
            return ESP_OK;
        }
    }
    // Create a new operator if capacity allows
    for (int i = 0; i < MAX_OPERATORS_PER_GROUP; ++i) {
        if (!s_group_op_pool[group][i].inited) {
            mcpwm_operator_config_t ocfg = { .group_id = group };
            ESP_RETURN_ON_ERROR(mcpwm_new_operator(&ocfg, &s_group_op_pool[group][i].oper), TAG_RC, "oper");
            ESP_RETURN_ON_ERROR(mcpwm_operator_connect_timer(s_group_op_pool[group][i].oper, s_group_timers[group].timer), TAG_RC, "connect");
            s_group_op_pool[group][i].inited = true;
            s_group_op_pool[group][i].used_generators = 1; // we'll assign one now
            *out_oper = s_group_op_pool[group][i].oper;
            ESP_LOGI(TAG_RC, "Initialized MCPWM operator %d for group %d (generators now %d)", i, group, s_group_op_pool[group][i].used_generators);
            return ESP_OK;
        }
    }
    ESP_LOGE(TAG_RC, "No free MCPWM operators/generators left in group %d (ops=%d, gens used: %d,%d)",
             group, MAX_OPERATORS_PER_GROUP,
             s_group_op_pool[group][0].used_generators,
             s_group_op_pool[group][1].used_generators);
    return ESP_ERR_NOT_FOUND;
}

// Constants for 50Hz hobby servo
#define SERVO_TIMEBASE_RESOLUTION_HZ 1000000  // 1 MHz
#define SERVO_TIMEBASE_PERIOD        20000    // 20 ms

// Simple clamp helper
static inline float clampf(float v, float lo, float hi) {
    return v < lo ? lo : (v > hi ? hi : v);
}
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

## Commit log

2026-03-01 move servo mainboard folder
    [hexapod.kicad_pcb, hexapod.kicad_sch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]
2026-05-02 mainboard kicad
    [esp32_connector.kicad_pcb, esp32_connector.kicad_sch, hexapod.kicad_pcb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]
2026-05-02 hardware gitignore and fixes
    [esp32_connector-job.gbrjob]
2026-05-03 extract kinematics, locomotion and config
2026-05-03 extract kinematics, locomotion and config part 2
2026-05-03 feat(config): add leg_geom namespace wiring and persistence
2026-05-04 docs: sync config and KPP status with current implementation
2026-05-04 Add controller config namespace and runtime wiring
2026-05-04 Implement wifi config namespace and runtime wiring
2026-05-12 namespace servo_map with gpio and driver selection
2026-05-12 config: add gait namespace and wire runtime consumers
2026-05-12 controller: add deadband and failsafe command profile
    [config_domain_controller_access.c, config_domain_controller_defaults.c, config_domain_controller_persistence_nvs.c]
2026-05-12 actuation: fail fast when joint calibration is missing or invalid
    [robot_control.c]
2026-05-13 first integration tests and compile fix
    [robot_control.c]
2026-05-13 leg geom namespace tests
2026-05-13 tests for motnion lim and servo map namespaces
2026-05-13 gait and joint_cal namespaces tests
2026-05-14 bottom plate design
    [hexapod.FCStd]
2026-05-15 top and bottom plates
    [hexapod.FCStd]
2026-05-24 new models
    [hexapod_v2.FCStd]
2026-05-27 fixed corner
    [hexapod_v2.FCStd]
2026-05-28 model updastes
    [hexapod_v2.FCStd]
2026-06-07 fixed a few thigs with model
    [hexapod_v2.FCStd, leg_v2.kicad_pcb, leg_v2.kicad_sch]
2026-06-09 chore: reorganize into firmware monorepo layout
    [partitions.csv]
2026-06-10 Add schematic-as-code framework and hardware-schematics skill
    Introduce hardware/schematic/, a pure-Python toolchain for authoring KiCad
    schematics from code while keeping UUIDs stable so existing PCB layouts are
    never lost (the PCB links each footprint by the schematic symbol UUID).
    - sexpr.py: lossless S-expression parser + KiCad-faithful serializer. Preserves
    each atom's source text so a board round-trips byte-for-byte and regeneration
    introduces zero UUID churn.
    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
2026-06-10 hardware: reorganize V1 boards into self-contained hardware/v1/
    Move the original (V1) electrical designs under hardware/v1/ so the version
    folders sit in parallel, mirroring the new hardware/v2/ layout:
    - servo_mainboard, leg, esp32_connector designs moved into hardware/v1/
    - v1 keeps its own copy of the symbol libraries (Seeed XIAO + SymbolsLib) and
    footprints (Seeed XIAO .pretty), so it no longer depends on shared top-level
    libraries
    - hexapod_v1.FCStd moved to hardware/v1/models/ (the v2 model stays put for now)
    - repoint the leg + esp32_connector sym/fp library tables to the local copies
    via ${KIPRJMOD}-relative paths (was an absolute C:/code/hexapod path)
    - add hardware/v1/READM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
    [esp32_connector.kicad_pcb, esp32_connector.kicad_sch, hexapod.kicad_pcb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]
2026-06-10 hardware: add V2 distributed-controller board schematics
    Add the Version 2 electrical design under hardware/v2/ as schematic-as-code,
    implementing the accepted V2 architecture (distributed leg controllers with
    logic power separated from servo power).
    Boards (Python source of truth + generated .kicad_sch + committed uuids.json):
    - mainboard - ESP32-WROOM-32D + IMU header + SP3485 RS485 master + 6x RJ11.
    Logic and communication only; no servo current.
    - legboard - XIAO RP2040 + SP3485 slave + 3 servo connectors + current/voltage
    sense header. One per leg; local PWM and interpolation.
    - powerboard - battery -> fuse/switch/reverse-polarity -> 3 UBEC + SBEC modul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
    [hexapod_v2.FCStd, legboard.kicad_sch, mainboard.kicad_sch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]
2026-06-10 skill(hardware-schematics): document gotchas and kicad-cli verification
    Capture lessons from authoring the V2 boards as code:
    - Gotchas section: an invalid global_label shape (e.g. shape="power") makes
    KiCad refuse to load the whole file with a generic error; harvesting flattened
    copies of derived (extends ...) stock symbols; stacked module pins sharing
    coordinates; rotation flipping pad order on two-pin passives; grid alignment.
    - "Does NOT do": import_lib_symbol cannot resolve (extends ...) derived symbols
    (they carry no pins), and find_all is non-recursive so you cannot import a
    symbol straight out of a .kicad_sch.
    - Verifying with kicad-cli: `sch erc` confirms the file loads;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
2026-06-10 move pin connection in rj11
    [legboard.kicad_sch]
2026-06-10 Update V2 board schematics and footprints
    [legboard.kicad_sch, mainboard.kicad_sch, powerboard.kicad_sch]
2026-06-10 Use 1210 footprint for legboard shunts
    [legboard.kicad_sch]
2026-06-11 latest leg schema changes
2026-06-11 LegBoard: Kelvin shunts for current sensing to fix sense-net routing
    Convert the four current-sense shunts (R2 total + R3/R4/R5 per-servo
    branches) from 2-terminal 0805/1210 resistors to 4-terminal Kelvin
    shunts (Device:R_Shunt, footprint Resistor_SMD:R_Shunt_Ohmite_LVK12).
    Why: the three branch shunts share one physical +6V source node, so all
    three INA4181 IN+ pins (U3 6/15/17) sat on the shared +6V net. The
    autorouter was free to bridge those high-side sense taps together and
    assign them current-rail trace widths. A 2-terminal shunt cannot fix
    this because force current and sense share the same pad/net.
    With Kelvin shunts the force pads (pins 1/4) carry the +6V rails while
    each sense pa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
    [legboard.kicad_sch]
2026-06-11 first iteration of leg board
    [legboard.kicad_pcb]
2026-06-13 manual fixes for mainboard
    [mainboard.kicad_pcb, mainboard.kicad_sch]
2026-06-13 revised mainbaord schematics
    [mainboard.kicad_pcb, mainboard.kicad_sch]
2026-06-15 powerboard changes
    [powerboard.kicad_pcb, powerboard.kicad_sch]
2026-06-15 firmware versioning applied
    [partitions.csv]
2026-06-15 docs: update README firmware paths to match v1/v2 versioning structure
    The firmware folder was restructured from firmware/mainboard/ and
    firmware/leg_v2/ to firmware/v1/mainboard/ and firmware/v2/leg/ to
    align with the hardware versioning schema. Update the directory tree
    and two links in README.md accordingly.
2026-06-15 docs: add research-backed bio-inspired locomotion roadmap to TODO
    Add a tiered "Bio-Inspired & Research-Backed Locomotion" section to the
    project TODO, upgrading the open-loop phase-table gait engine toward
    biologically-grounded, continuously-adaptive locomotion. Each item cites
    published research and is anchored to the specific code it touches.
    - Tier 1 (pure software, v1): Wilson gait continuum, CPG coupled-oscillator
    gait engine, minimum-impact quintic swing trajectory.
    - Tier 2 (needs v2 IMU): body-attitude auto-leveling, stumble/elevator reflex.
    - Tier 3 (needs v2 per-leg current sensing): Tegotae force-feedback gaits.
    Also wires the new items into the Phase 2/3 priority lists.
    Co-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
2026-06-15 docs: extend locomotion roadmap with follow-up ideas and analysis items
    Second wave of research-backed locomotion items, sorted by the user's
    guidance on priority and readiness.
    Scheduled items:
    - Holonomic body velocity (lateral vy / crab walk) added to Tier 1 (software).
    - Self-righting / flip-back recovery added to Tier 2 (IMU), third priority.
    - Walknet added to Tier 3 as a lowest-priority A/B-toggle ALTERNATIVE to
    Tegotae (the two decentralized schemes likely cannot run concurrently).
    New "Needs Analysis" subsection (promising but not yet scoped):
    - Static stability margin / support-polygon-aware foot placement.
    - Manipulability- / singularity-aware posture optimization.
    - Phase-res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
2026-06-20 leg v2
    [hexapod_v2.FCStd]
2026-06-20 powerboard layout
    [powerboard.kicad_pcb, powerboard.kicad_sch]
2026-06-20 powerboard layout adjustments
    [powerboard.kicad_pcb]
2026-06-20 powerboard rc1
    [powerboard.kicad_pcb]
2026-06-21 mainboard physical design
    [mainboard.kicad_pcb, mainboard.kicad_sch]
2026-06-22 new docs
    [partitions.csv]
2026-06-23 feat(v2): add RS485 leg-bus master, strip PWM from actuation
    V2 mainboard now drives legs over RS485 instead of generating servo PWM
    directly. The ESP32 forwards joint angles to the six RP2040 LegBoards; each
    RP2040 owns its own PWM, calibration, offsets, and limits.
    - hex_rs485_master: new component owning UART2 as an RS485 half-duplex bus
    master (TX=IO17, RX=IO16, DE=IO4 as hardware RTS, 1 Mbps). Runs its own
    FreeRTOS task polling all six legs sequentially, independent of the 100 Hz
    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
2026-06-23 feat(v2): implement RP2040 LegBoard firmware
    One binary for all six legs (address in flash). RS485 slave: receives
    joint-angle targets from the ESP32 master, interpolates locally, drives three
    servos, samples per-servo current, answers every pull with telemetry, and holds
    position on bus silence (watchdog).
    Modules (arduino-pico / Pico SDK):
    - protocol: CRC-8/SMBus + frame parse/build, byte-for-byte compatible with the
    master; hardware-independent and host-testable (test/host/).
    - rs485: UART0 half-duplex with manual DE turnaround that polls the UART BUSY
    flag before releasing DE (arduino-pico has no hardware auto-DE; avoids
    truncating the final CRC byte at 1 Mbps).
    - interp: LINEAR (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
2026-06-23 fix(v2): emit WATCHDOG_ACTIVE on recovery; correct INTERP_MODE doc default
    - Leg latches the watchdog state and reports WATCHDOG_ACTIVE on the first
    response after the bus returns, so the master learns the leg held position
    during the silence (while in watchdog the leg sends nothing, so this is the
    only chance to surface the bit).
    - RS485_PROTOCOL.md: INTERP_MODE default corrected to 00 (LINEAR). The leg
    boots LINEAR for bring-up and the master never auto-sends the mode, so CUBIC
    is opt-in via P03 — the previous "default 01/CUBIC" was misleading.
2026-07-12 legboard sensing corrections and shunt remapping
    - Fix INA4181A3IPWR gain: was 3 (copy-paste error), correct value is 100
    per datasheet (A3 suffix = gain 100); V_TO_A scale was ~33x too high
    - Remap shunt resistors for better PCB layout: R4=total, R5=coxa,
    R3=femur, R2=tibia (was R2=total, R3=coxa, R4=femur, R5=tibia)
    - Update ADC pin assignments on XIAO to match new shunt layout:
    A0=total, A1=femur, A2=tibia, A3=coxa
    - Add leg firmware test sketch (tibia servo sweep + current readout)
    targeting XIAO RP2040 via PlatformIO; kept for v2 board validation
    [legboard.kicad_pcb, legboard.kicad_sch]
2026-07-12 mainboard physical design and body model update
    [hexapod_v2.FCStd, mainboard.kicad_pcb]
2026-07-12 docs: update legboard net table and add PCB order tagging convention
    - Correct shunt/channel/ADC assignments after remapping (R4=total,
    R3=femur, R2=tibia, R5=coxa; A1=femur, A2=tibia, A3=coxa)
    - Note INA4181A3IPWR gain = 100 in the net description
    - Add PCB order tagging section: git tags named pcb_order_<JLCPCB-ID>
    mark the exact commit sent to manufacture for each board order
2026-07-12 firmware: stall test with per-servo and total current safety
    Old-board ADC mapping (A0=total, A1=coxa, A3=tibia; femur CH3 dead).
    Adds auto-zero baseline at startup and safety watchdog: branch trip at
    3 A detaches the offending servo, total trip at 9 A cuts all; both
    followed by 2 s cooldown and re-attach so the test cycle continues.
2026-07-12 firmware: update ADC mapping for new legboard revision
    New board: A0=total, A1=femur, A2=tibia, A3=coxa (matches schematic).
    All four channels now active; TOTAL_CORR removed (layout underread fixed
    in new spin).
2026-07-14 firmware: fix RS485 DE-turnaround self-echo drop on legboard, add bring-up benchmark tool
    The legboard's rs485_send() released the RS485 DE line without draining the
    UART RX FIFO, letting a turnaround glitch byte get consumed as a bogus empty
    line on the next poll and silently eat every other pull frame. Confirmed via
    hardware bring-up (~50% response loss, deterministic alternating pattern) and
    fixed by draining the FIFO right after DE release.
    Adds firmware/v2/mainboard_rs485_test, a standalone ESP-IDF app (independent
    of the full gait-framework mainboard build) used to bring up and benchmark
    the RS485 link against a single physical leg, plus its measured round-trip
    timing in docs/v2/inter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
    [main.c]
2026-07-14 hardware: fix legboard current-sense channel mapping, swap powerboard PMOS to IRF9540NPBF
    Legboard: correct the INA4181 stub labels so U3 pins 2-4/13-15 map to
    TOTAL/TIBIA current sensing per the corrected net table, instead of the
    swapped TOTAL<->TIBIA assignment.
    Powerboard: replace Q1/Q2 reverse-polarity PMOS (FQP47P06 -> IRF9540NPBF).
    [legboard.kicad_pcb, legboard.kicad_sch, powerboard.kicad_sch]
2026-07-17 hardware: replace F1 main fuse holder with soldered SMD fuse
    TME stocks no SMD automotive blade-fuse holder, and the THT mini-blade
    holder was awkward to hand-solder. Switch F1 to Schurter 3413.0331.22
    (1206 SMD, 20A, time-lag), soldered directly with a stock KiCad
    Fuse_1206_3216Metric footprint -- non-replaceable, but a blown fuse on
    the main battery input means a fault needs tracing anyway.
    [powerboard.kicad_sch]
2026-07-19 powerboard updates
    [hexapod_v2.FCStd, powerboard.kicad_pcb]
2026-07-31 Remove v2 hardware/firmware/docs, flatten v1 into top-level layout
    Version 2 (RS485/RP2040 distributed leg controllers) has moved to
    github.com/quick-brown-bot/hexapod_v2. This repo now covers only the
    original ESP32 direct-PWM robot, so the v1/v2 split is gone:
    hardware/firmware/docs v1 subfolders are flattened to the top level,
    and all v2 content is removed.
    Also drops the mostly-v2 TODO backlog, notes that v1 is closed
    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
    [esp32_connector.kicad_pcb, esp32_connector.kicad_sch, hexapod.kicad_pcb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]
